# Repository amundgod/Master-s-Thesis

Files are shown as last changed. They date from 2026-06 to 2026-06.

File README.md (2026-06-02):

# Master-s-Thesis
This is the repo for the master's thesis by Amund Godal. 

The repo consists of STEP-files, INO-code, and test data in form of pressure data, boolean funtionality data, and force measurement data. The data is presented in its raw form, which is the basis for plots in the thesis itself. The boolean and force data is logged inside MS Excel.

The INO code is the code used for the entire replanting sequence. To test the individual sub-systems one could use this as a basis to separate out disired test objects.

The STEP files could be imported into CAD software to be visualized or produced to test. The DXF for cutting out a needle for the substrate gripper is also available here.

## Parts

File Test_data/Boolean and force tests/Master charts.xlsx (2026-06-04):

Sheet: Integrated Test
Integrated test
Test # | Seed Pickup | n. Seed | Seed Type | Pickup | Placement | New Plug | Used Plug | Compound
1 | 1 | 2 | L | 1 | 1 | 1 | 1
2 | 1 | 3 | L | 1 | 1 | 1 | 1
3 | 1 | 3 | L | 1 | 1 | 1 | 0
4 | 1 | 2 | L | 1 | 1 | 1 | 1
5 | 1 | 3 | L | 1 | 1 | 1 | 1
6 | 1 | 2 | L | 1 | 1 | 1 | 1
7 | 1 | 4 | B | 1 | 1 | 1 | 0
8 | 1 | 3 | B | 1 | 1 | 1 | 1
9 | 1 | 4 | B | 1 | 1 | 1 | 1
10 | 1 | 4 | B | 1 | 1 | 1 | 0
Success [%] | 100 |  |  | 100 | 100 | 100 | 70 | 70
Root cutting: | 0.47
Current: | 0.7
Compound: | 0.33 | = | 32.66666667 | %
L= Lettuce
B= Basil

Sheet: SeedTest
Seed Pickups | Fail = 0 | Success = 1
Seed type | Ordinary basil | n Seeds | Kale | n Seeds | Green lettuce | n Seeds
Test #
1 | 1 | 3 | 1 | 3 | 1 | 1
2 | 1 | 3 | 1 | 1 | 1 | 1
3 | 1 | 3 | 1 | 1 | 1 | 3
4 | 1 | 3 | 1 | 1 | 1 | 1
5 | 1 | 3 | 1 | 1 | 1 | 2
6 | 1 | 3 | 1 | 1 | 1 | 1
7 | 1 | 4 | 1 | 1 | 1 | 2
8 | 1 | 2 | 1 | 1 | 1 | 3
9 | 1 | 2 | 1 | 1 | 1 | 2
10 | 1 | 3 | 1 | 1 | 1 | 4
11 | 1 | 3 | 1 | 1 | 1 | 1
12 | 1 | 3 | 1 | 1 | 1 | 1
13 | 1 | 3 | 1 | 1 | 1 | 1
14 | 1 | 2 | 1 | 1 | 1 | 3
15 | 1 | 3 | 1 | 1 | 1 | 1
16 | 1 | 3 | 1 | 1 | 1 | 2
17 | 1 | 3 | 1 | 1 | 1 | 2
18 | 1 | 2 | 1 | 1 | 1 | 1
19 | 1 | 3 | 1 | 1 | 1 | 2
20 | 1 | 3 | 1 | 1 | 1 | 1
Average: | 1 | 2.85 | 1 | 1.1 | 1 | 1.75
Std. dev | 0 | 0.49 | 0.00 | 0.45 | 0.00 | 0.91
Aerated | Ordinary basil | n Seeds | Kale | n Seeds | Green lettuce | n Seeds
1 |  | 1 |  | 1 |  | 1
2 |  | 1 |  | 1 |  | 1
3 |  | 1 |  | 1 |  | 2
4 |  | 1 |  | 1 |  | 1
5 |  | 1 |  | 1 |  | 1
6 |  | 1 |  | 1 |  | 1
7 |  | 1 |  | 1 |  | 1
8 |  | 1 |  | 1 |  | 1
9 |  | 1 |  | 1 |  | 1
10 |  | 1 |  | 1 |  | 1
11 |  | 1 |  | 1 |  | 1
12 |  | 2 |  | 1 |  | 1
13 |  | 1 |  | 1 |  | 2
14 |  | 1 |  | 1 |  | 1
15 |  | 1 |  | 1 |  | 1
16 |  | 1 |  | 1 |  | 1
17 |  | 1 |  | 1 |  | 1
18 |  | 1 |  | 1 |  | 1
19 |  | 1 |  | 1 |  | 1
20 |  | 1 |  | 1 |  | 1
Average: |  | 1.05 |  | 1 |  | 1.1
Std. dev |  | 0.2236067977 |  | 0.00 |  | 0.31

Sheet: Root Cutter Test
Root Cutter Final Test
Test # | Plug Growth[weeks] | Success(0/1) | Runs | Fail Node
1 | 5 | 1 | 3
2 | 5 | 0 | 5 | Deflection
3 | 5 | 1 | 4
4 | 5 | 1 | 3
5 | 5 | 0 | 5 | Deflection
6 | 3 | 0 | 5 | Deflection
7 | 3 | 1 | 2
8 | 3 | 1 | 4
9 | 3 | 0 | 5 | Deflection
10 | 3 | 1 | 3
11 | 2 | 0 | 5 | Deflection
12 | 2 | 0 | 5 | Deflection
13 | 2 | 1 | 2
14 | 4 | 1 | 3
15 | 4 | 0 | 5 | Deflection
16 | 4 | 0 | 5 | Deflection
17 | 4 | 0 | 5 | Deflection
Sucess avg. |  | 0.47

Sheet: Dry Substrate Test
Unused Dry Substrate 3 mm steel needle
Test # | Depth [cm] | Max Read [g] | Force Max [N] | Success (0/1)
1 | 1 | 2600 | 25.51 | 1
2 | 1 | 2680 | 26.29 | 1
3 | 1 | 2500 | 24.52 | 1
4 | 1 | 2550 | 25.02 | 1
5 | 1 | 2400 | 23.54 | 1
6 | 1 | 2650 | 26.00 | 1
7 | 1 | 2900 | 28.45 | 1
8 | 1 | 2630 | 25.80 | 1
9 | 1 | 2800 | 27.47 | 1
10 | 1 | 2630 | 25.80 | 1
11 | 2 | 4300 | 42.18 | 1
12 | 2 | 4400 | 43.16 | 1
13 | 2 | 3600 | 35.32 | 1
14 | 2 | 3990 | 39.14 | 1
15 | 2 | 4200 | 41.20 | 1
16 | 2 | 4600 | 45.13 | 1
17 | 2 | 4530 | 44.44 | 1
18 | 2 | 4450 | 43.65 | 1
19 | 2 | 4300 | 42.18 | 1
20 | 2 | 4200 | 41.20 | 1
21 | 3 | 4930 | 48.36 | 1
22 | 3 | 4980 | 48.85 | 1
23 | 3 | 4270 | 41.89 | 1
24 | 3 | 4960 | 48.66 | 1
25 | 3 | 4650 | 45.62 | 1
26 | 3 | 4900 | 48.07 | 1
27 | 3 | 4720 | 46.30 | 1
28 | 3 | 4660 | 45.71 | 1
29 | 3 | 4990 | 48.95 | 1
30 | 3 | 4800 | 47.09 | 1
Unused Moist Substrate
Test # | Depth [cm] | Force Max [g] | Force Max [N] | Success (0/1) | Damage (0-3)
1 | 1 | 530 | 5.20 | 1 | 0
2 | 1 |  | 0.00 |  | 0
3 | 1 |  | 0.00 |  | 0
4 | 1 |  | 0.00 |  | 0
5 | 1 |  | 0.00 |  | 0
6 | 1 |  | 0.00 |  | 0
7 | 1 |  | 0.00 |  | 0
8 | 1 |  | 0.00 |  | 0
9 | 1 |  | 0.00 |  | 0
10 | 1 |  | 0.00 |  | 0
11 | 2 | 700 | 6.87 | 1 | 0
12 | 2 |  | 0.00 |  | 1
13 | 2 |  | 0.00 |  | 0
14 | 2 |  | 0.00 |  | 0
15 | 2 |  | 0.00 |  | 1
16 | 2 |  | 0.00 |  | 0
17 | 2 |  | 0.00 |  | 0
18 | 2 |  | 0.00 |  | 0
19 | 2 |  | 0.00 |  | 0
20 | 2 |  | 0.00 |  | 1
21 | 3 | 770 | 7.55 | 1 | 2
22 | 3 |  | 0.00 |  | 1
23 | 3 |  | 0.00 |  | 2
24 | 3 |  | 0.00 |  | 3
25 | 3 |  | 0.00 |  | 2
26 | 3 |  | 0.00 |  | 2
27 | 3 |  | 0.00 |  | 3
28 | 3 |  | 0.00 |  | 2
29 | 3 |  | 0.00 |  | 3
30 | 3 |  | 0.00 |  | 2
31 | 4 | 1900 | 18.64 | 1
32 | 4 |  | 0.00
33 | 4 |  | 0.00
34 | 4 |  | 0.00
35 | 4 |  | 0.00
36 | 4 |  | 0.00
37 | 4 |  | 0.00
38 | 4 |  | 0.00
39 | 4 |  | 0.00
40 | 4 |  | 0.00

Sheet: Used Substrate Test
Used Plug Test
Test # | Plugstate | Success | Fail | Dig Length [cm]
1 | UG | 0 | Split | 3.75
2 | G | 1 |  | 3.75
3 | G | 1 |  | 3.75
4 | OG | 1 |  | 3.75
5 | OG | 1 |  | 3.75
6 | M | 1 |  | 3.75
7 | M | 1 |  | 3.75
8 | M | 0 | Split | 3.75
9 | M | 1 |  | 3.75
10 | M | 0 | Split | 3.75
M = moist
UG = Undergrown
G = Grown
OG = Overgrown

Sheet: PlugDim
Plug Size and Deviations
Plug # | Outer inscribed | Mean Deviation | Deviation | Middle hole | Mean Deviation | Center Distance
1.00 | 32.47 | 32.47 | 0.47 | 10.33 | 10.33 | 1.62
2.00 | 32.17 | 32.17 | 0.17 | 10.72 | 10.72 | 1.39
3.00 | 31.93 | 31.93 | -0.07 | 10.66 | 10.66 | 2.30
4.00 | 32.05 | 32.05 | 0.05 | 10.29 | 10.29 | 0.45
5.00 | 32.20 | 32.20 | 0.20 | 10.41 | 10.41 | 1.69
6.00 | 31.68 | 31.68 | -0.32 | 9.84 | 9.84 | 1.14
7.00 | 32.57 | 32.57 | 0.57 | 10.53 | 10.53 | 0.99
8.00 | 31.81 | 31.81 | -0.19 | 9.94 | 9.94 | 0.92
9.00 | 31.46 | 31.46 | -0.54 | 9.99 | 9.99 | 0.40
10.00 | 31.84 | 31.84 | -0.16 | 10.21 | 10.21 | 1.21
11.00 | 32.02 | 32.02 | 0.02 | 10.15 | 10.15 | 0.80
12.00 | 32.27 | 32.27 | 0.27 | 10.00 | 10.00 | 1.12
13.00 | 32.07 | 32.07 | 0.07 | 10.37 | 10.37 | 1.00
14.00 | 32.27 | 32.27 | 0.27 | 10.05 | 10.05 | 0.71
Std.dev | 0.29 | 0.29 | 0.29 | 0.26 | 0.26 | 0.49
Mean | 32.06 |  |  | 10.25 |  | 1.12
Nominal | 32.00 |  |  | 10.00

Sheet: Substrate Depth Test
Substrate insertion depth test
Test | Insertion Depth | Pickup | Fail Node
1 | 10 | 0 | No Pickup
2 | 15 | 0 | No Pickup
3 | 20 | 0 | No Pickup
4 | 25 | 0 | No Pickup
5 | 30 | 0 | No Pickup
6 | 35 | 1
7 | 35 | 0 | No Pickup
8 | 35 | 1
9 | 35 | 0 | No Pickup
10 | 37.5 | 0 | Plug Split
11 | 37.5 | 1
12 | 37.5 | 1
13 | 37.5 | 1
14 | 40 | 0 | Plug Split
15 | 40 | 1
16 | 40 | 1
17 | 40 | 0 | Plug Split
18 | 42.5 | 0 | Plug Split
19 | 42.5 | 1
20 | 42.5 | 0 | Plug Split
21 | 42.5 | 0 | Plug Split

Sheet: Plug Cup Gripper Test
Cup Load Test
Test # | Small Weights | Large Weights | Total Load[kg] | Total Load [N] | Deflection[mm]
1 | 1 | 5 | 10.4 | 102.0 | 4
2 | 2 | 4 | 9 | 88.3 | 3.5
3 | 0 | 5 | 9.85 | 96.6 | 4
4 | 1 | 4 | 8.45 | 82.9 | 3.5
5 | 1 | 5 | 10.4 | 102.0 | 4.5
Weights [kg] | Small | Large | Setup Excess
 | 0.55 | 1.95 | 0.1

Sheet: Component Costs
Unit costs
Part | Cost/unit |  | Amount | Cost |  | Link
Differential Pressure | 270 | kr | 1 | 270 | kr | https://no.rs-online.com/web/p/pressure-sensor-ics/7191103
Micro Switch | 176 | kr | 1 | 176 | kr | https://no.rs-online.com/web/p/micro-switches/2496861
Stainless Steel Rod | 97 | kr | 1 | 97 | kr | https://no.rs-online.com/web/p/tubing-and-profile-struts/7866006
Stepper motor w/lead screw | 452 | kr | 2 | 904 | kr | https://www.prusa3d.com/product/stepper-motor-z-axis-left-2/
Comressed air pipe | 394 | kr | 1 | 394 | kr | https://no.rs-online.com/web/p/air-hoses/0225892
Sparkfun Vacuum Pump | 250 | kr | 1 | 250 | kr | https://www.sparkfun.com/vacuum-pump-12v.html
Lead Screw nut | 75 | kr | 2 | 150 | kr | https://www.prusa3d.com/product/trapezoid-nut-i3-mk4-mmu2-2s-3/
kanyle G19X1 1/2 | 106 | kr | 1 | 106 | kr | https://www.apotek1.no/produkter/sterican-kanyle-g19x1-1-2-1.10x40mm-100stk-920975p
NPN Transistor | 71 | kr | 1 | 71 | kr | https://no.rs-online.com/web/p/darlington-pairs/4369779
Parallax Inc Standard Servo | 231 | kr | 2 | 462 | kr | https://no.rs-online.com/web/p/servo-motors/7813058
MG-90S Micro servo | 149 | kr | 1 | 149 | kr | https://mrsmart.no/mg-90s-mikroservo-180-grader-girkasse-i-metall-id81
Razor blade | 60 | kr | 1 | 60 | kr | https://www.jula.no/catalog/bygg-og-maling/maling-og-fugemasse/tekstil-og-tapet/tapetseringsverktoy/barberblad-014966/
Linear Ball Bearing | 290 | kr | 1 | 290 | kr | https://no.rs-online.com/web/p/linear-bearings/0576637
Row Ball Bearing 8 mm ID | 76 | kr | 2 | 152 | kr | https://no.rs-online.com/web/p/ball-bearings/2346922
Row Ball Bearing 25 mm ID | 369 | kr | 1 | 369 | kr | https://no.rs-online.com/web/p/ball-bearings/2850611
Adafriut Metro |  |  |  | 226 | kr | https://no.rs-online.com/web/p/microcontroller-development-tools/1245519
Total: |  |  |  | 4126 | kr
Actual Bought
Part | Cost/unit |  | Amount | Cost |  | Link
Differential Pressure | 270 | kr | 1 | 270 | kr | https://no.rs-online.com/web/p/pressure-sensor-ics/7191103
Micro Switch | 176 | kr | 1 | 176 | kr | https://no.rs-online.com/web/p/micro-switches/2496861
Comressed air pipe | 394 | kr | 1 | 394 | kr | https://no.rs-online.com/web/p/air-hoses/0225892
Sparkfun Vacuum Pump | 250 | kr | 1 | 250 | kr | https://www.sparkfun.com/vacuum-pump-12v.html
kanyle G19X1 1/2 | 106 | kr | 1 | 106 | kr | https://www.apotek1.no/produkter/sterican-kanyle-g19x1-1-2-1.10x40mm-100stk-920975p
Parallax Inc Standard Servo | 231 | kr | 2 | 462 | kr | https://no.rs-online.com/web/p/servo-motors/7813058
Razor blade | 60 | kr | 1 | 60 | kr | https://www.jula.no/catalog/bygg-og-maling/maling-og-fugemasse/tekstil-og-tapet/tapetseringsverktoy/barberblad-014966/
Linear Ball Bearing | 290 | kr | 1 | 290 | kr | https://no.rs-online.com/web/p/linear-bearings/0576637
Row Ball Bearing 25 mm ID | 369 | kr | 1 | 369 | kr | https://no.rs-online.com/web/p/ball-bearings/2850611
Total: |  |  |  | 2377 | kr

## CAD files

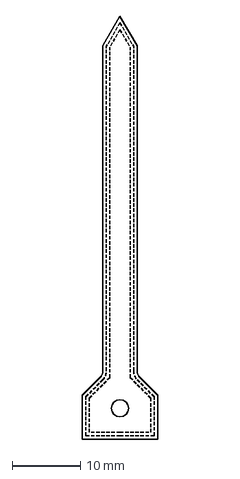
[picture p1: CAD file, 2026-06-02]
STEP-files/NeedleDXF.dxf
11.0 x 62.0 mm

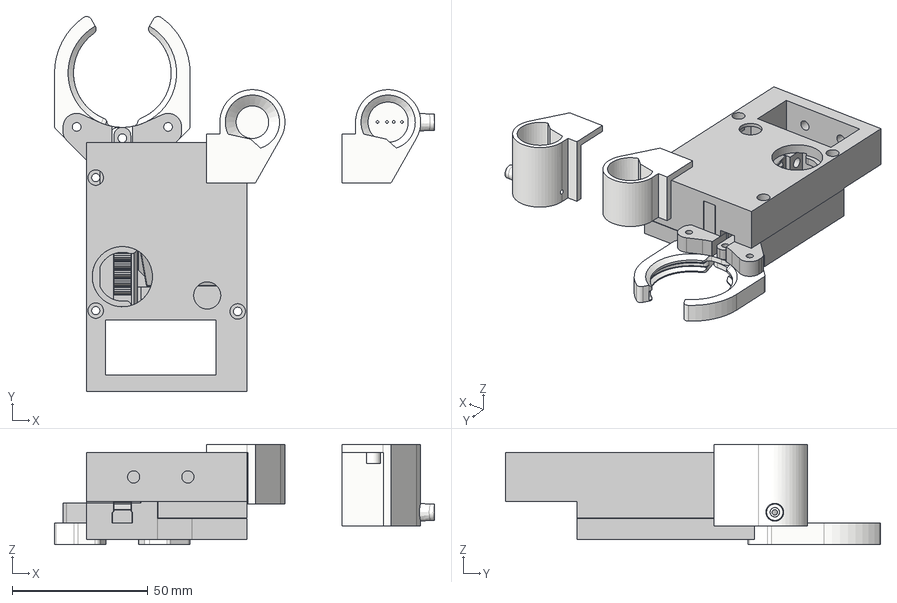
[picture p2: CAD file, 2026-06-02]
STEP-files/CupGripper.step
140.0 x 138.2 x 36.9 mm
servo_moteur
Rack Gear (12 teeth)
Spur Gear (12 teeth)
Right Finger
Left Finger
Arm
Button

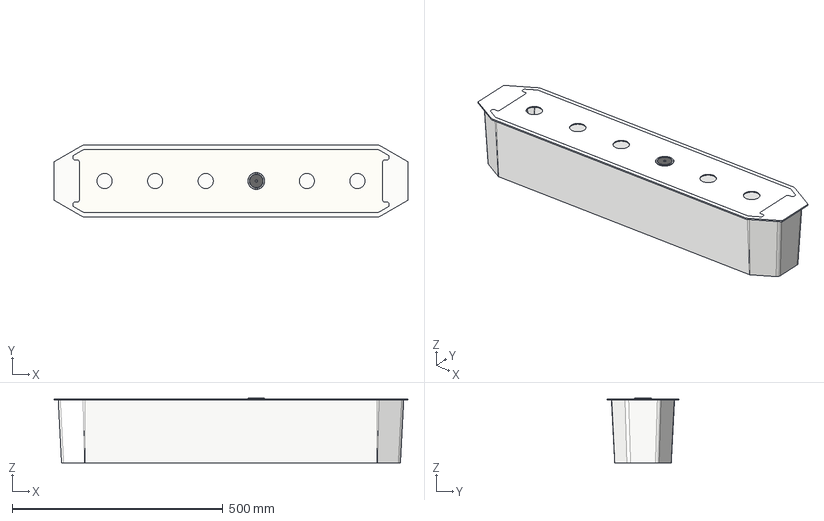
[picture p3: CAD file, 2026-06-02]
STEP-files/HarvyTestSystem.step
840.0 x 170.0 x 153.5 mm
Soil plug
Plug Cup

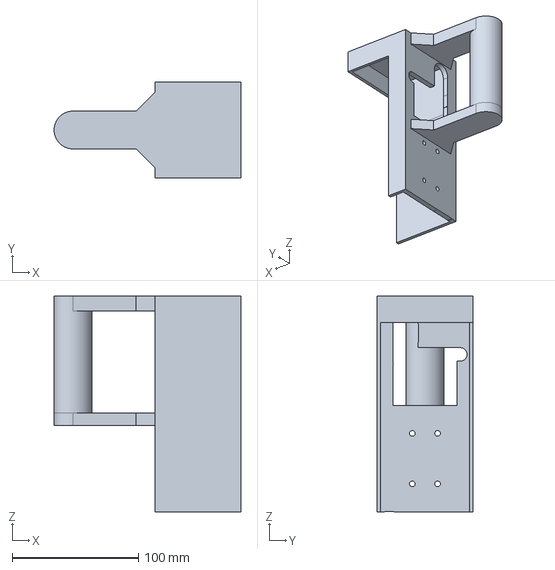
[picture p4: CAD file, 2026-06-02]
STEP-files/OperatorHandle.step
148.0 x 76.2 x 171.1 mm

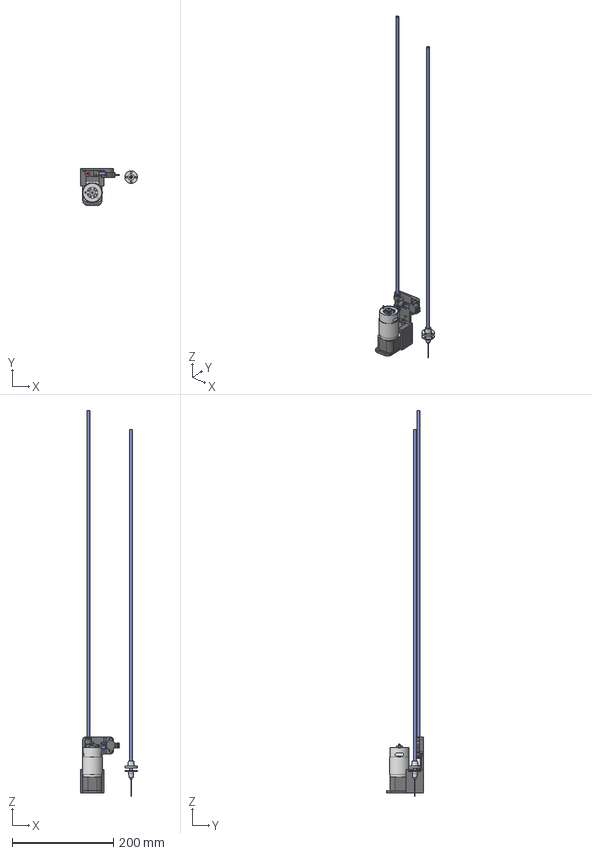
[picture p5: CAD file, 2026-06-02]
STEP-files/SeedPlacer.step
112.4 x 73.8 x 762.5 mm
Ø6 UNIÃO T (C00600600)
SPARKFUN_VACUUM_PUMP
Parametric Needle
mpx2050

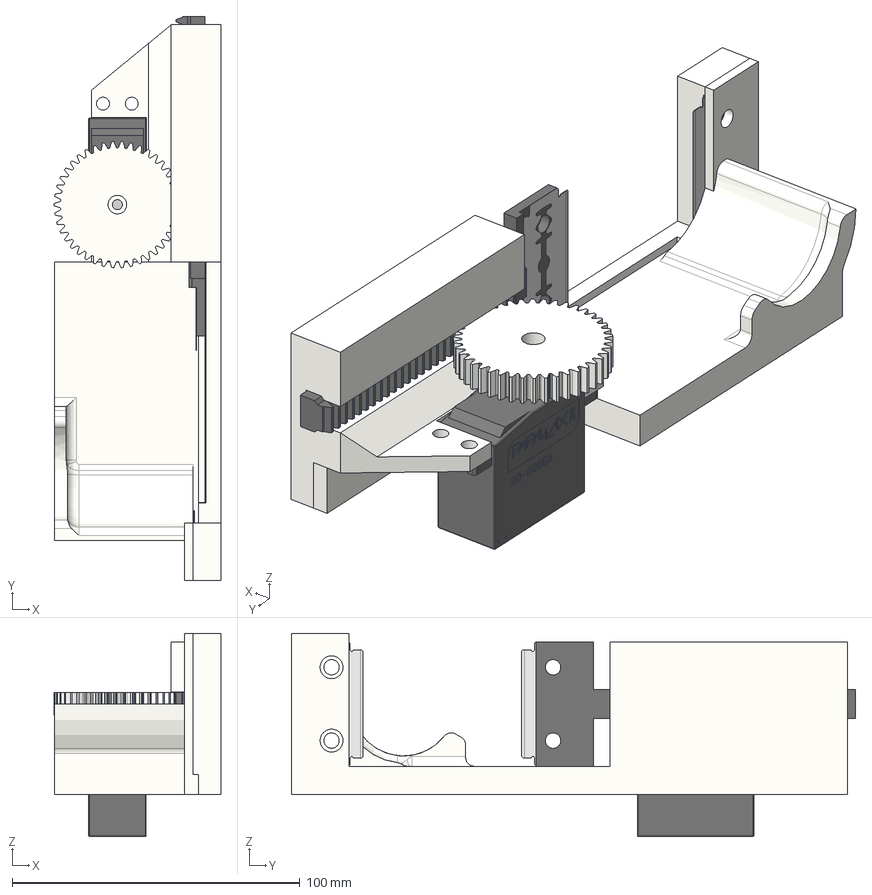
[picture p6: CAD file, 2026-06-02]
STEP-files/RootCutter.step
58.0 x 196.3 x 70.6 mm
servo_moteur
Palonnier
Spur Gear (42 teeth)
Rack Gear (30 teeth)
CollabCAD 4 x 2

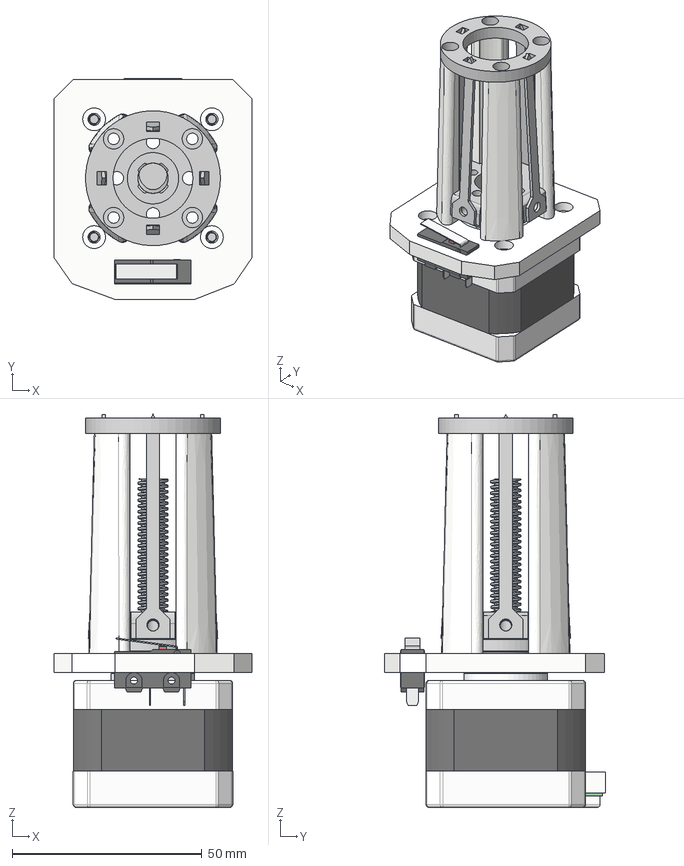
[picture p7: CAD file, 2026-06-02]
STEP-files/SubstrateGripper.step
52.0 x 58.1 x 103.4 mm
Nema 17
Arm
Button
Guide
Lead Screw
screw nut 8mm
Needles x 4

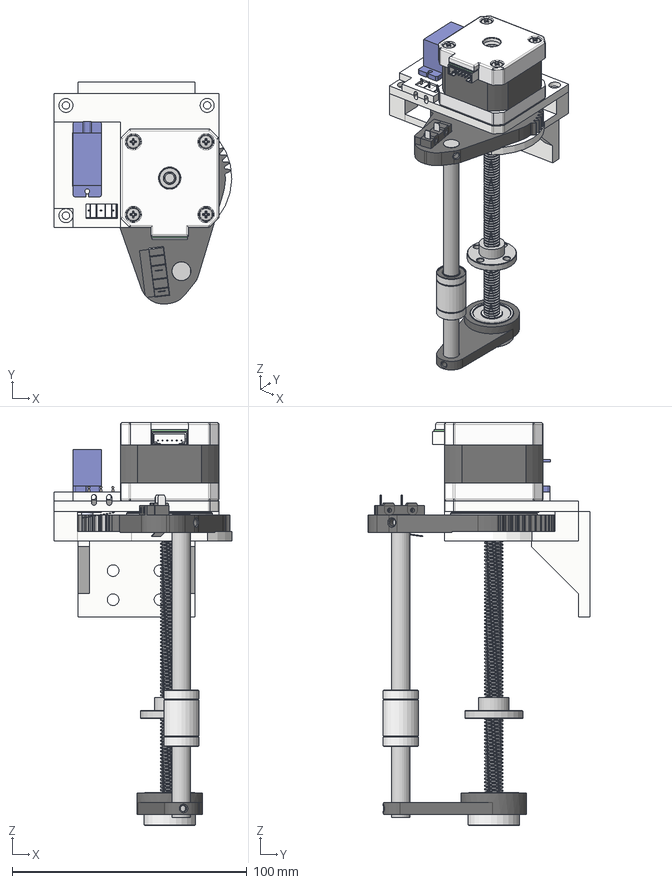
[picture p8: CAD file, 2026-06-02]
STEP-files/MechanicalMovement.step
75.7 x 94.7 x 171.8 mm
Nema 17
Support Shaft
Lead Screw
8 ID 22 OD x 2
Spur Gear (50 teeth)
25 mm ID bearing
Gear Top Shell
Linear Bearing 8 mm ID
screw nut 8mm
Spur Gear (25 teeth)
Micro_servo_FS90
Gear Shell 2
Lower arm
Arm
Button
Low_Part
High_Part
Button_1
Short_Lever
Mount bracket

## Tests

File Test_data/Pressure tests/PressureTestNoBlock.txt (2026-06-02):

Time_s,Pump,Pressure_kPa
0.0,1,-4.53
0.2,1,-1.00
0.4,1,2.45
0.6,1,5.66
0.8,1,8.61
1.0,1,11.37
1.2,1,13.85
1.4,1,16.20
1.6,1,18.14
1.8,1,20.00
2.0,1,21.46
2.2,1,22.55
2.4,1,23.54
2.6,1,24.53
2.8,1,25.59
3.0,1,26.65
3.2,1,27.61
3.4,1,28.63
3.6,1,29.33
3.8,1,29.86
4.0,1,30.55
4.2,1,31.00
4.4,1,31.20
4.6,1,31.37
4.8,1,31.58
5.0,1,31.88
5.2,1,32.32
5.4,1,32.70
5.6,1,33.16
5.8,1,33.52
6.0,1,33.74
6.2,1,34.04
6.4,1,34.09
6.6,1,33.87
6.8,1,33.72
7.0,1,33.70
7.2,1,33.68
7.4,1,33.87
7.6,1,34.11
7.8,1,34.32
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

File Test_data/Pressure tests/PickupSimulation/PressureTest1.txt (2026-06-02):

Time_s,Pump,Pressure_kPa
0.0,1,-8.98
0.2,1,-2.99
0.4,1,4.18
0.6,1,11.08
0.8,1,17.23
1.0,1,22.77
1.2,1,27.75
1.4,1,32.18
1.6,1,36.22
1.8,1,39.86
2.0,1,43.13
2.2,1,46.18
2.4,1,48.82
2.6,1,51.26
2.8,1,53.44
3.0,1,55.36
3.2,1,57.13
3.4,1,58.68
3.6,1,60.18
3.8,1,61.53
4.0,1,62.74
4.2,1,63.78
4.4,1,64.72
4.6,1,65.56
4.8,1,66.26
5.0,1,66.95
5.2,1,67.57
5.4,1,68.12
5.6,1,68.57
5.8,1,69.03
6.0,0,69.38
6.2,0,69.21
6.4,0,68.41
6.6,0,67.09
6.8,0,65.20
7.0,0,62.84
7.2,0,60.07
7.4,0,56.98
7.6,0,53.60
7.8,0,49.96
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

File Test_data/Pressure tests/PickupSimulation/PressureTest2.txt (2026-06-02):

Time_s,Pump,Pressure_kPa
0.0,1,-8.98
0.2,1,-3.27
0.4,1,3.40
0.6,1,9.61
0.8,1,15.26
1.0,1,20.39
1.2,1,25.07
1.4,1,29.33
1.6,1,33.11
1.8,1,36.57
2.0,1,39.74
2.2,1,42.59
2.4,1,45.16
2.6,1,47.52
2.8,1,49.70
3.0,1,51.61
3.2,1,53.33
3.4,1,54.82
3.6,1,56.27
3.8,1,57.47
4.0,1,58.55
4.2,1,59.52
4.4,1,60.50
4.6,1,61.33
4.8,1,62.02
5.0,1,62.59
5.2,1,63.26
5.4,1,63.87
5.6,1,64.31
5.8,1,64.75
6.0,0,65.21
6.2,0,64.21
6.4,0,61.74
6.6,0,57.93
6.8,0,53.15
7.0,0,47.87
7.2,0,43.07
7.4,0,38.74
7.6,0,34.91
7.8,0,31.40
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

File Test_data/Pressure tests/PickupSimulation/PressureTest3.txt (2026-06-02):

Time_s,Pump,Pressure_kPa
0.0,1,-8.98
0.2,1,-2.72
0.4,1,4.10
0.6,1,10.57
0.8,1,16.45
1.0,1,21.84
1.2,1,26.70
1.4,1,31.02
1.6,1,34.96
1.8,1,38.56
2.0,1,41.69
2.2,1,44.62
2.4,1,47.25
2.6,1,49.46
2.8,1,51.55
3.0,1,53.44
3.2,1,55.03
3.4,1,56.51
3.6,1,57.85
3.8,1,59.11
4.0,1,60.24
4.2,1,61.26
4.4,1,62.23
4.6,1,63.10
4.8,1,63.78
5.0,1,64.44
5.2,1,65.04
5.4,1,65.47
5.6,1,65.91
5.8,1,66.30
6.0,0,66.77
6.2,0,65.99
6.4,0,63.99
6.6,0,60.89
6.8,0,56.90
7.0,0,52.33
7.2,0,47.13
7.4,0,42.46
7.6,0,38.25
7.8,0,34.46
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

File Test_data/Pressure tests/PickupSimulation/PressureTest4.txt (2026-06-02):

Time_s,Pump,Pressure_kPa
0.0,1,-8.98
0.2,1,-3.16
0.4,1,3.60
0.6,1,10.23
0.8,1,16.36
1.0,1,22.03
1.2,1,27.04
1.4,1,31.59
1.6,1,35.64
1.8,1,39.28
2.0,1,42.55
2.2,1,45.56
2.4,1,48.15
2.6,1,50.60
2.8,1,52.74
3.0,1,54.67
3.2,1,56.46
3.4,1,58.02
3.6,1,59.53
3.8,1,60.73
4.0,1,61.92
4.2,1,62.98
4.4,1,63.89
4.6,1,64.76
4.8,1,65.49
5.0,1,66.14
5.2,1,66.79
5.4,1,67.31
5.6,1,67.84
5.8,1,68.26
6.0,0,68.75
6.2,0,68.32
6.4,0,67.01
6.6,0,64.90
6.8,0,62.14
7.0,0,58.79
7.2,0,54.90
7.4,0,50.64
7.6,0,46.10
7.8,0,41.47
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

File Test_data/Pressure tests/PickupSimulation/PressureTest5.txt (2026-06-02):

Time_s,Pump,Pressure_kPa
0.0,1,-5.99
0.2,1,-1.94
0.4,1,3.02
0.6,1,8.56
0.8,1,14.10
1.0,1,19.29
1.2,1,23.92
1.4,1,27.97
1.6,1,31.67
1.8,1,34.90
2.0,1,38.01
2.2,1,40.82
2.4,1,43.29
2.6,1,45.51
2.8,1,47.62
3.0,1,49.47
3.2,1,51.18
3.4,1,52.67
3.6,1,53.90
3.8,1,55.12
4.0,1,56.27
4.2,1,57.20
4.4,1,58.08
4.6,1,58.94
4.8,1,59.60
5.0,1,60.30
5.2,1,60.88
5.4,1,61.40
5.6,1,61.92
5.8,1,62.44
6.0,0,62.80
6.2,0,61.66
6.4,0,58.85
6.6,0,54.63
6.8,0,49.58
7.0,0,44.66
7.2,0,40.23
7.4,0,36.24
7.6,0,32.65
7.8,0,29.37
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

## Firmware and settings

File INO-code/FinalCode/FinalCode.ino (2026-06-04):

#include <Servo.h>

// ===== STEPPER 1 =====
const int dirPin1      = 2;
const int stepPin1     = 3;
const int enablePin1   = 8;
const int limitSwitch1 = 7;

// ===== STEPPER 2 =====
const int dirPin2      = 6;
const int stepPin2     = 4;
const int enablePin2   = 10;
const int limitSwitch2 = 11;

// ===== GANTRY SERVO =====
const int gantryServoPin    = 9;
const int limitSwitchGantry = A2;

// ===== GRIPPER SERVO =====
const int gripperServoPin    = 5;
const int limitSwitchGripper = A1;

// ===== CUTTING SERVO =====
const int cuttingServoPin = 13;

// ===== PUMP =====
const int pumpPin = 12;

// ===== PRESSURE SENSOR =====
const int pressureSensor = A0;

// ===== TRIGGER BUTTON =====
const int triggerPin = A4;

// ===== STEPPER SETTINGS =====
const float stepsPerRevolution = 400.0; // steps per revolution for steppers
const int moveDelay1 = 300;             // gantry movement speed
const int moveDelay2 = 300;             // substrate gripper movement speed
const int slowDelay  = 500;             // gantry and substrate homing speed
const int safeOffset = 80;              // offset from microswitches

// ===== USED PLUG CALIBRATION =====
const float plug_stepper1_downRounds = 10.2;                          // rounds down to pick used substrate
const float plug_stepper2_diglength  = 3.75;                           // [cm] dig length
const float plug_stepper2_digRounds  = plug_stepper2_diglength / 0.8; // substrate gripper dig depth for used substrate

// ===== NEW PLUG & SEED CALIBRATION =====
const float stepper1_firstDownRounds  = 10.0; // rounds down to pick unused substrate
const float stepper1_secondDownRounds = 10.0; // rounds down to place unused substrate
const float stepper1_upRounds         = 3.0;  // rounds up after picking seed
const float stepper1_thirdDownRounds  = 5.0;  // rounds down to drop-off seed
const float stepper2_downRounds       = 2.0;  // substrate gripper dig for unused substrate

// ===== CUTTING SERVO CALIBRATION =====
const int cuttingStartAngle = 30;  // resting angle for cutter
const int cuttingEndAngle   = 150; // end angle for cutter
const int cuttingPauseMs    = 500; // resting time for cutter

// ===== GANTRY SERVO CALIBRATION =====
const int gantryHomingSpeed   = 10;  // ms pause per degree during homing sweep
const int gantrySafeOffset    = 23;  // degrees to back off after switch triggers
const int gantryHomeAngle     = 23;  // startup write angle before homing
const int gantryRestAngle     = 0;   // rest position relative to zero
const int gantryDiscardAngle  = 160; // angle of dropping substrate
const int gantrySeedPick      = 120;  // seed drop-off position
const int gantrySubstratePick = 160; // angle for picking new substrate
const int gantryMinDelay      = 2;   // ms per degree at peak speed
const int gantryMaxDelay      = 10;  // ms per degree at start/end

// ===== GRIPPER SERVO CALIBRATION =====
const int gripperHomingSpeed = 15; // ms per degree for homing gripper
const int gripperSafeOffset  = 5;  // offset from trigger switch
const int gripperOpenAngle   = 80; // open gripper position
const int gripperGripAngle   = 25; // angle for gripping substrate plug

// ===== PRESSURE CALIBRATION =====
const float V_MIN                   = 0.1727; // pressure offset
const float V_RANGE                 = 4.5;    // operating range of sensor
const float P_MAX                   = 500.0;  // maximum pressure measurement
const float pressureClogLimit       = 40.0;   // threshold for clog test
const float pressurePickedThreshold = 50.0;   // threshold for pickup sensing
const float pressureDropThreshold   = 50.0;   // threshold for dropped seed
const float pressureAlpha           = 0.1;    // smoothing factor
const int   clogTestDuration        = 5000;   // duration of clog test

// ===== SEED PICKUP RETRY =====
const int          seedPickupRetries = 2;     // extra attempts after first failure
const unsigned long pickupWait       = 4000;  // ms to wait before oscillating
const unsigned long pickupMax        = 10000; // ms total per attempt before giving up

// ===== OBJECTS =====
Servo gantryServo;
Servo gripperServo;
Servo cuttingServo;

// ===== STATE =====
bool stepper1Homed     = false;
bool stepper2Homed     = false;
bool pumpActive        = false;
int  gantryZero        = 0;   // absolute angle where gantry switch triggered + offset
int  gripperZero       = 0;   // absolute angle where gripper switch triggered - offset
float pressureSmoothed = 0;   // running EMA of raw pressure ADC reading

// Step position tracking — counts steps below home, always >= 0
long stepper1Pos = 0;
long stepper2Pos = 0;

// ===== HELPERS =====

// Converts float revolution count to integer step count for A4988 driver
long roundsToSteps(float rounds) {
  return (long)(rounds * stepsPerRevolution);
}

// Prevents servo write values from going outside 0-180 degree hardware limit
int clampAngle(int angle) {
  if (angle < 0)   return 0;
  if (angle > 180) return 180;
  return angle;
}

// Issues a single step pulse to the A4988 driver on the given step pin
void stepMotor(int sPin, int delayVal) {
  digitalWrite(sPin, HIGH);
  delayMicroseconds(delayVal);
  digitalWrite(sPin, LOW);
  delayMicroseconds(delayVal);
}

// Moves a stepper a fixed number of steps without position tracking or switch checking.

void moveStepsRaw(int sPin, int dPin, long steps, bool dirUp, int delayVal, int enPin) {
  if (steps <= 0) return;
  digitalWrite(enPin, LOW);
  digitalWrite(dPin, dirUp ? HIGH : LOW);
  for (long i = 0; i < steps; i++) {
    stepMotor(sPin, delayVal);
  }
  digitalWrite(enPin, HIGH);
}

// Moves stepper 1 by the given number of steps while tracking absolute position.
// On every upward step, checks the limit switch — if triggered unexpectedly,
void moveStepper1(long steps, bool dirUp) {
  if (steps <= 0) return;
  digitalWrite(enablePin1, LOW);
  digitalWrite(dirPin1, dirUp ? HIGH : LOW);

  for (long i = 0; i < steps; i++) {
    if (dirUp && digitalRead(limitSwitch1) == LOW) {
      digitalWrite(enablePin1, HIGH);
      Serial.println("ERROR: Stepper 1 hit limit switch unexpectedly. Check mechanism.");
      moveStepsRaw(stepPin1, dirPin1, safeOffset, false, slowDelay, enablePin1);
      stepper1Pos = safeOffset;
      return;
    }
    stepMotor(stepPin1, moveDelay1);
    stepper1Pos += dirUp ? -1 : 1;
    if (stepper1Pos < 0) stepper1Pos = 0;
  }

  digitalWrite(enablePin1, HIGH);
}

// Moves stepper 2 by the given number of steps while tracking absolute position.
// On every upward step, checks the limit switch

void moveStepper2(long steps, bool dirUp) {
  if (steps <= 0) return;
  digitalWrite(enablePin2, LOW);
  digitalWrite(dirPin2, dirUp ? HIGH : LOW);

  for (long i = 0; i < steps; i++) {
    if (dirUp && digitalRead(limitSwitch2) == LOW) {
      digitalWrite(enablePin2, HIGH);
      Serial.println("ERROR: Stepper 2 hit limit switch unexpectedly. Check mechanism.");
      moveStepsRaw(stepPin2, dirPin2, safeOffset, false, slowDelay, enablePin2);
      stepper2Pos = safeOffset;
      return;
    }
    stepMotor(stepPin2, moveDelay2);
    stepper2Pos += dirUp ? -1 : 1;
    if (stepper2Pos < 0) stepper2Pos = 0;
  }

  digitalWrite(enablePin2, HIGH);
}

// Returns stepper 1 exactly as many steps upward as it currently is below home, then resets position tracker to zero
void returnStepper1() {
  if (stepper1Pos <= 0) return;
  moveStepper1(stepper1Pos, true);
  stepper1Pos = 0;
}

// Returns stepper 2 exactly as many steps upward as it currently is below home, then resets position tracker to zero.
void returnStepper2() {
  if (stepper2Pos <= 0) return;
  moveStepper2(stepper2Pos, true);
  stepper2Pos = 0;
}

// Drives stepper toward limit switch, waits for trigger, backs off safeOffset steps, and sets position tracker to safeOffset
void homeStepper(int sPin, int dPin, int sw, int enPin, bool &homedFlag, long &posTracker) {
  digitalWrite(enPin, LOW);
  if (digitalRead(sw) == LOW) {
    digitalWrite(dPin, LOW);
    while (digitalRead(sw) == LOW) stepMotor(sPin, slowDelay);
  }
  digitalWrite(dPin, HIGH);
  while (digitalRead(sw) == HIGH) stepMotor(sPin, slowDelay);
  digitalWrite(enPin, HIGH);
  moveStepsRaw(sPin, dPin, safeOffset, false, slowDelay, enPin);
  posTracker = safeOffset;
  homedFlag = true;
}

// Blocks execution until the physical trigger button is pressed and released. with debounce

void waitForPress(const char* message) {
  Serial.println(message);
  while (digitalRead(triggerPin) == LOW);
  while (digitalRead(triggerPin) == HIGH);
  delay(50);
}

// ===== PRESSURE =====

// Converts ADC voltage to absolute pressure in kPa using sensor-specific offset and range constants.
float voltageToPressure(float voltage) {
  return ((voltage - V_MIN) / V_RANGE) * P_MAX;
}

// Reads ADC, applies exponential moving average smoothing, converts to voltage then to kPa and returns the result.
float readPressure() {
  int raw = analogRead(pressureSensor);
  pressureSmoothed = pressureAlpha * raw + (1.0 - pressureAlpha) * pressureSmoothed;
  float voltage = pressureSmoothed * (5.0 / 1023.0);
  return voltageToPressure(voltage);
}

// Runs pump for clogTestDuration ms and monitors pressure.
// If pressure exceeds pressureClogLimit the program halts: blockage .
void runClogTest() {
  pressureSmoothed = analogRead(pressureSensor);
  digitalWrite(pumpPin, HIGH);

  unsigned long start = millis();
  float maxP = 0;

  while (millis() - start < (unsigned long)clogTestDuration) {
    float p = readPressure();
    if (p > maxP) maxP = p;

    if (p > pressureClogLimit) {
      digitalWrite(pumpPin, LOW);
      Serial.print("ERROR: Clog detected at ");
      Serial.print(p);
      Serial.println(" kPa. Clear blockage and reset.");
      while (true);
    }
    delay(200);
  }

  digitalWrite(pumpPin, LOW);
}

// ===== GANTRY SERVO =====

// Drives gantry servo toward decreasing angle until limit switch triggers,
// then backs off gantrySafeOffset degrees.

void homeGantry() {
  int angle = gantryServo.read();

  while (digitalRead(limitSwitchGantry) == HIGH) {
    angle--;
    if (angle < 0) {
      angle = 0;
      gantryServo.write(0);
      Serial.println("WARNING: Gantry switch not found. Using angle 0 as reference.");
      delay(300);
      gantryZero = 0;
      moveGantryTo(gantryHomeAngle);
      return;
    }
    gantryServo.write(angle);
    delay(gantryHomingSpeed);
  }

  angle = clampAngle(angle + gantrySafeOffset);
  gantryServo.write(angle);
  delay(300);
  gantryZero = angle;

  moveGantryTo(gantryHomeAngle);
}

// Moves gantry servo to a position expressed as degrees from gantryZero. Uses a sinusoidal speed profile

void moveGantryTo(int degreesFromZero) {
  int target  = clampAngle(gantryZero + degreesFromZero);
  int current = gantryServo.read();
  int steps   = abs(target - current);
  if (steps == 0) return;
  int dir = (target > current) ? 1 : -1;

  for (int i = 0; i < steps; i++) {
    current += dir;
    gantryServo.write(current);
    float progress = (float)i / (steps - 1);
    int d = (int)(gantryMinDelay + (gantryMaxDelay - gantryMinDelay) * (1.0 - sin(PI * progress)));
    delay(d);
  }
}

// ===== GRIPPER SERVO =====

// Drives gripper servo toward increasing angle until limit switch triggers, then backs off gripperSafeOffset degrees. 

void homeGripper() {
  int angle = gripperServo.read();

  while (digitalRead(limitSwitchGripper) == HIGH) {
    angle++;
    if (angle > 180) {
      angle = 180;
      gripperServo.write(angle);
      Serial.println("WARNING: Gripper switch not found.");
      break;
    }
    gripperServo.write(angle);
    delay(gripperHomingSpeed);
  }

  angle = clampAngle(angle - gripperSafeOffset);
  gripperServo.write(angle);
  delay(300);
  gripperZero = angle;
}

// Moves gripper to a position expressed as degrees subtracted from gripperZero

void moveGripperTo(int degreesFromZero, int msPerDegree = 10) {
  int target  = clampAngle(gripperZero - degreesFromZero);
  int current = gripperServo.read();
  int step    = (target > current) ? 1 : -1;

  while (current != target) {
    current += step;
    gripperServo.write(clampAngle(current));
    delay(msPerDegree);
  }
}

// ===== CUTTING SERVO =====

// Executes five full cutting strokes by sweeping between cuttingStartAngle and cuttingEndAngle
void performCut() {
  cuttingServo.write(cuttingStartAngle); delay(cuttingPauseMs);
  cuttingServo.write(cuttingEndAngle);   delay(cuttingPauseMs);
  cuttingServo.write(cuttingStartAngle); delay(cuttingPauseMs);
  cuttingServo.write(cuttingEndAngle);   delay(cuttingPauseMs);
  cuttingServo.write(cuttingStartAngle); delay(cuttingPauseMs);
  cuttingServo.write(cuttingEndAngle);   delay(cuttingPauseMs);
  cuttingServo.write(cuttingStartAngle); delay(cuttingPauseMs);
  cuttingServo.write(cuttingEndAngle);   delay(cuttingPauseMs);
  cuttingServo.write(cuttingStartAngle);
}

// ===== EMERGENCY HOME =====

// Called on any unrecoverable error. Stops pump, re-homes both steppers via limit switches
void goToHome() {
  digitalWrite(pumpPin, LOW);
  pumpActive = false;
  homeStepper(stepPin1, dirPin1, limitSwitch1, enablePin1, stepper1Homed, stepper1Pos);
  homeStepper(stepPin2, dirPin2, limitSwitch2, enablePin2, stepper2Homed, stepper2Pos);
  moveGantryTo(gantryRestAngle);
  moveGripperTo(gripperOpenAngle);
  Serial.println("ERROR: System homed after failure. Reset to restart.");
}

// ===== SEED PICKUP =====

// Single pickup attempt. Waits pickupWait ms stationary for pressure to rise.

bool tryPickupSeed() {
  unsigned long start = millis();

  while (millis() - start < pickupWait) {
    if (readPressure() >= pressurePickedThreshold) return true;
    delay(200);
  }

  while (millis() - start < pickupMax) {
    if (readPressure() >= pressurePickedThreshold) return true;
    moveStepper1(roundsToSteps(0.5), true);
    if (readPressure() >= pressurePickedThreshold) return true;
    moveStepper1(roundsToSteps(0.5), false);
  }

  return false;
}

// Calls tryPickupSeed() up to seedPickupRetries + 1 times.

void waitForSeedPickup() {
  for (int attempt = 0; attempt <= seedPickupRetries; attempt++) {
    if (tryPickupSeed()) return;
  }
  Serial.println("ERROR: Seed pickup failed after all retries.");
  goToHome();
  while (true);
}

// Reads pressure and triggers emergency home if below pressureDropThreshold, indicating seed was lost during transport.
void checkPressureOrHome() {
  float p = readPressure();
  if (p < pressureDropThreshold) {
    Serial.print("ERROR: Pressure dropped to ");
    Serial.print(p);
    Serial.println(" kPa — seed lost.");
    goToHome();
    while (true);
  }
}

// ===== SETUP =====
void setup() {
  pinMode(dirPin1,      OUTPUT);
  pinMode(stepPin1,     OUTPUT);
  pinMode(enablePin1,   OUTPUT);
  pinMode(limitSwitch1, INPUT_PULLUP);

  pinMode(dirPin2,      OUTPUT);
  pinMode(stepPin2,     OUTPUT);
  pinMode(enablePin2,   OUTPUT);
  pinMode(limitSwitch2, INPUT_PULLUP);

  pinMode(limitSwitchGantry,  INPUT_PULLUP);
  pinMode(limitSwitchGripper, INPUT_PULLUP);
  pinMode(triggerPin,         INPUT_PULLUP);

  pinMode(pumpPin, OUTPUT);
  digitalWrite(pumpPin,    LOW);
  digitalWrite(enablePin1, HIGH);
  digitalWrite(enablePin2, HIGH);

  Serial.begin(9600);
  while (!Serial);

  delay(100);
  gantryServo.attach(gantryServoPin);
  gripperServo.attach(gripperServoPin);
  cuttingServo.attach(cuttingServoPin);
  gantryServo.write(gantryHomeAngle);
  gripperServo.write(90);
  cuttingServo.write(cuttingStartAngle);
  delay(100);

  homeStepper(stepPin1, dirPin1, limitSwitch1, enablePin1, stepper1Homed, stepper1Pos);
  homeStepper(stepPin2, dirPin2, limitSwitch2, enablePin2, stepper2Homed, stepper2Pos);
  homeGantry();
  homeGripper();
  moveGripperTo(gripperOpenAngle);

  runClogTest();
  pressureSmoothed = analogRead(pressureSensor);

  Serial.println("Ready.");
}

// ===== LOOP =====
void loop() {
  static bool done = false;
  if (done) return;

  // ===== PHASE 1: USED PLUG REMOVAL =====

  waitForPress("Press button to begin.");

  moveGripperTo(gripperGripAngle);
  delay(1000);

  moveGantryTo(gantryHomeAngle);
  delay(100);

  moveStepper1(roundsToSteps(plug_stepper1_downRounds), false);

  moveStepper2(roundsToSteps(plug_stepper2_digRounds), false);
  delay(1000);                                                    // for end effector to reach root cutter

  performCut();

  returnStepper1();

  moveGantryTo(gantryDiscardAngle);
  delay(100);

  moveStepper1(roundsToSteps(stepper1_firstDownRounds), false);

  returnStepper2();
  delay(100);

  // ===== PHASE 2: NEW PLUG & SEED =====

  moveGantryTo(gantrySubstratePick);
  delay(2500);

  moveStepper2(roundsToSteps(stepper2_downRounds), false);
  delay(100);

  returnStepper1();

  moveGantryTo(gantryHomeAngle);

  moveStepper1(roundsToSteps(stepper1_secondDownRounds), false);

  returnStepper2();
  delay(100);

  digitalWrite(pumpPin, HIGH);
  pumpActive = true;
  delay(100);

  waitForSeedPickup();

  moveStepper1(roundsToSteps(stepper1_upRounds), true);
  checkPressureOrHome();
  delay(100);

  moveGantryTo(gantrySeedPick);
  checkPressureOrHome();
  delay(100);

  moveStepper1(roundsToSteps(stepper1_thirdDownRounds), false);
  checkPressureOrHome();
  delay(100);

  digitalWrite(pumpPin, LOW);
  pumpActive = false;
  delay(1500);

  returnStepper1();
  delay(100);

  moveGantryTo(gantryHomeAngle);

  moveGripperTo(gripperOpenAngle);
  delay(100);

  done = true;
  Serial.println("Cycle complete. Reset to run again.");
}

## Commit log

2026-06-02 Needle import
    [NeedleDXF.dxf]
2026-06-03 Update Excel
    [Master charts.xlsx, Test_results.xlsx]
2026-06-03 Excel cleaning
    [Master charts.xlsx]
2026-06-04 Excel polishing
    [Master charts.xlsx]
